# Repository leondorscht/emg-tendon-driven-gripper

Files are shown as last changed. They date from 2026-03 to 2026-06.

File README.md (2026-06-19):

# EMG Tendon-Driven Gripper

Tendon-driven robotic gripper with EMG-based open/close control. An automated Python pipeline handles calibration, threshold computation, and Arduino firmware flashing — no manual configuration needed.

Gripper Demo Video (https://youtu.be/KU1vd0XyC_Q)

---

## System Overview

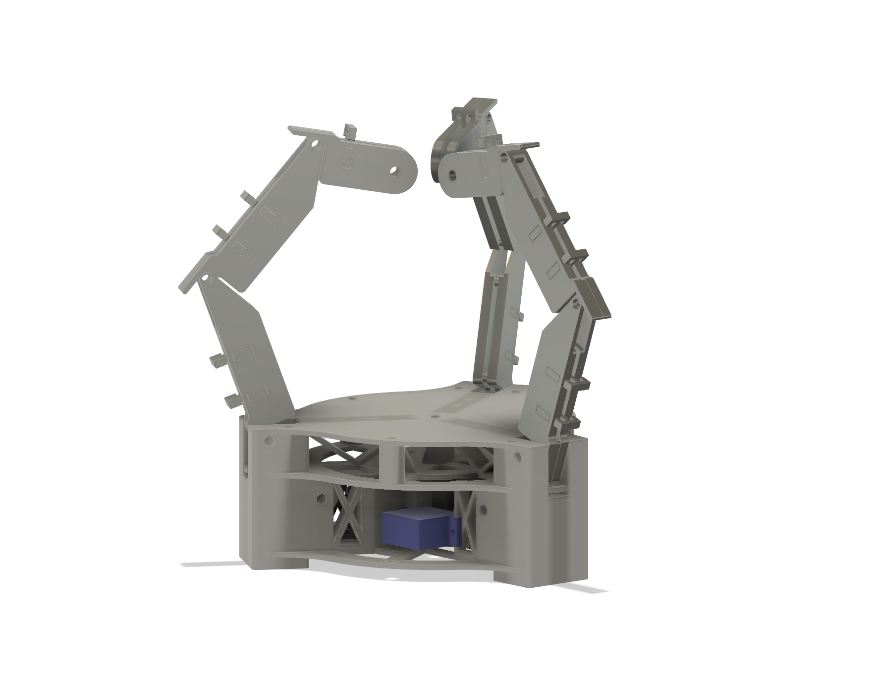
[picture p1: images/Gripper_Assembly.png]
Assembly View


*Figure 1 – Servo-based gripper assembly.*

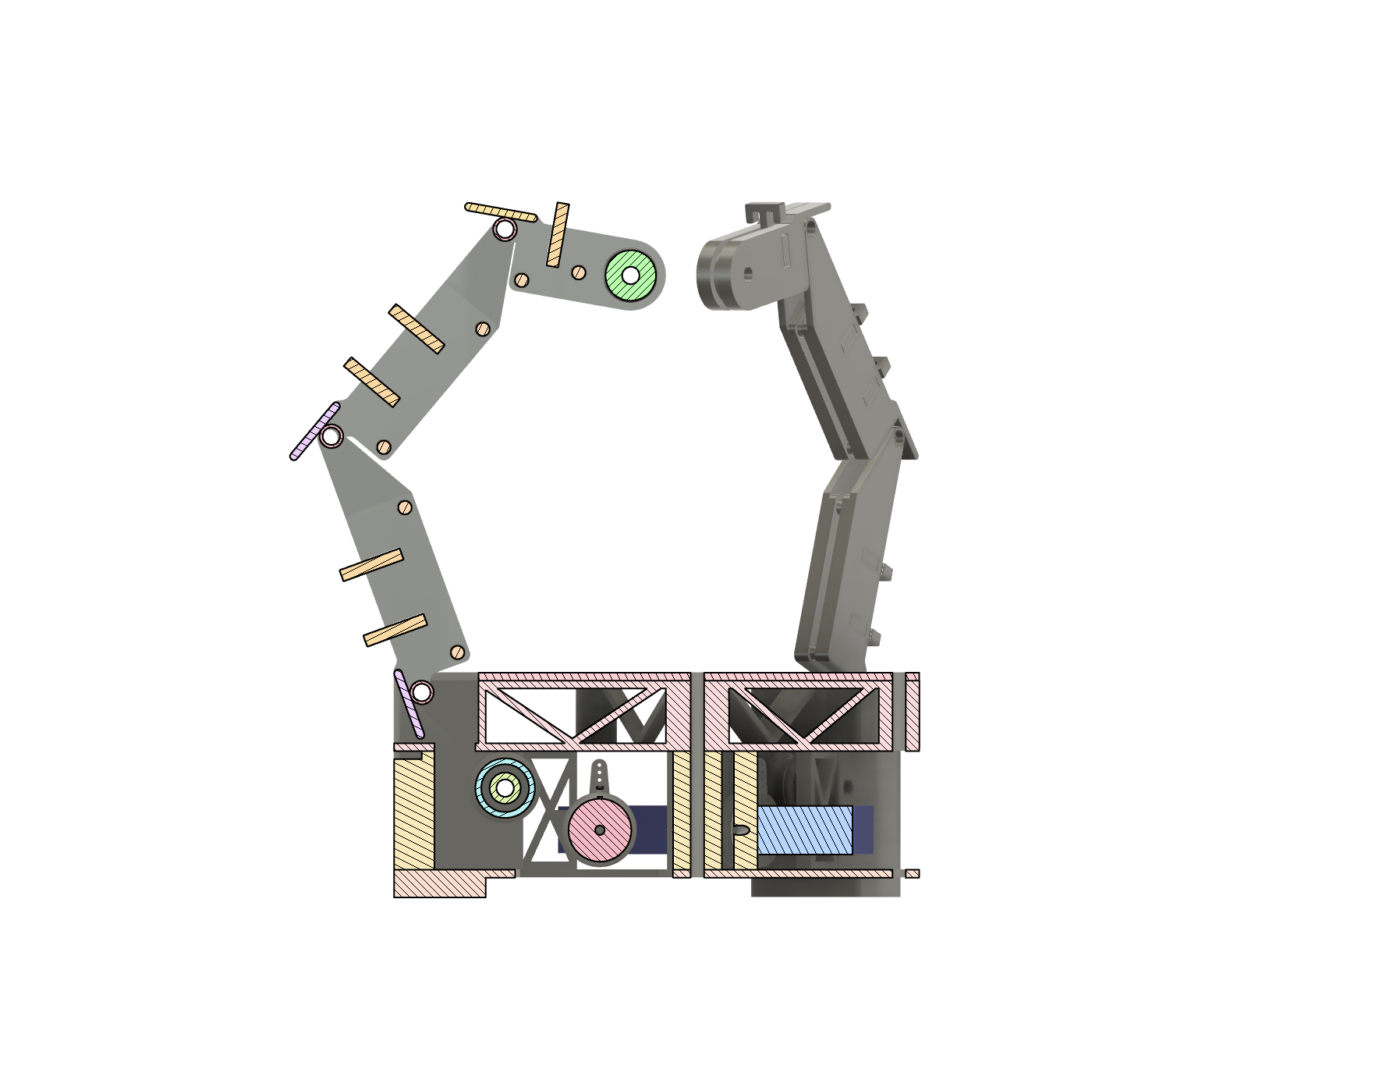
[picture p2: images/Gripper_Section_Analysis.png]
Section View


*Figure 2 – Section view highlighting internal structure, bearings and actuator integration.*

---

## Design Reference

The mechanical concept of the gripper is inspired by the tendon-driven underactuated gripper presented in:

Yi, J., Kim, B., Cho, K.-J., & Park, Y.-L. (2023).  
**Underactuated Robotic Gripper With Fiber-Optic Force Sensing Tendons.**  
IEEE Robotics and Automation Letters, 8(11), 7607–7614.  
https://doi.org/10.1109/LRA.2023.3315204

This project is **not a direct reproduction** of the original system.  
Instead, the CAD model adapts key mechanical ideas from the paper into a simplified prototype intended for rapid prototyping with 3D printing, servo-based actuation, and EMG-based control.

---

## Repository Structure

```
emg-tendon-driven-gripper/
├── arduino/
│   └── emg_controller/
│       ├── emg_controller.ino   # Arduino sketch (calibration + control modes)
│       └── config.h             # Auto-generated hardware config (do not edit manually)
├── cad/
│   ├── gripper_v1_(legacy)/     # V1 cycloidal drive concept (STEP)
│   └── gripper_v2/              # V2 servo-based design (STEP, 3MF, STL)
├── data/
│   └── calibration.csv          # EMG calibration recording output
├── images/
├── python/
│   ├── run_pipeline.py          # End-to-end pipeline entry point
│   ├── calibration_recorder.py  # EMG serial reader, protocol generator, CSV recorder
│   ├── threshold_calculator.py  # RMS-based threshold from calibration data
│   ├── config_writer.py         # Writes arduino/emg_controller/config.h
│   └── arduino_flasher.py       # Compiles and uploads via arduino-cli
└── requirements.txt
```

---

## Signal Processing

EMG control relies on two steps: baseline removal and RMS feature extraction.

**Baseline removal** – during calibration, the median of all rest-state samples is computed and stored as `EMG_BASELINE`. In control mode, the Arduino subtracts this value from each raw ADC reading before computing RMS, removing the DC offset introduced by the sensor circuit (~340 ADC on the DFRobot Gravity EMG sensor).

**RMS (Root Mean Square)** – the signal energy over a sliding window of `RMS_WINDOW` centered samples is computed as:

```
RMS = sqrt( mean( (x - baseline)^2 ) )
```

RMS is more robust than a simple mean threshold because mean values are almost identical between rest and contraction states (both dominated by the DC offset), while RMS captures the increase in signal variance during muscle activation.

**Threshold** – computed from rest-state RMS values as:

```
threshold = rest_RMS_mean + multiplier × rest_RMS_std
```

With the default `multiplier = 2.0`, approximately 97.7% of rest-state RMS values fall below the threshold. A sanity check warns if the computed threshold exceeds the active-state RMS mean, indicating a failed calibration.

**State detection** – to avoid false triggers from transient spikes, the control loop requires the RMS to exceed the threshold for `ACTIVATION_COUNT_THRESHOLD` consecutive samples before closing, and to fall below it for `RELEASE_COUNT_THRESHOLD` consecutive samples before opening.

---

## Software Pipeline

The Python pipeline in `python/run_pipeline.py` automates the full calibration-to-control workflow:

1. **Write calibration config** – generates `config.h` with `MODE_CALIBRATION=1` and a passthrough threshold
2. **Flash calibration firmware** – compiles and uploads the sketch via `arduino-cli`
3. **Record calibration data** – guides the user through a rest/active protocol and records raw EMG values to CSV
4. **Compute threshold and baseline** – calculates `EMG_BASELINE` (median of rest values) and `EMG_THRESHOLD` (rest RMS mean + multiplier × rest RMS std) from the recorded data
5. **Write control config** – regenerates `config.h` with `MODE_CALIBRATION=0`, the computed threshold, and the baseline
6. **Flash control firmware** – uploads the final sketch; the Arduino now runs RMS-based EMG threshold control

### Arduino firmware modes

The sketch switches behaviour at compile time via `MODE_CALIBRATION` in `config.h`:

- **Calibration mode** – streams raw ADC values over serial at ~200 Hz; Python handles all signal processing
- **Control mode** – computes RMS on-device after baseline subtraction, closes all servos when `rms_value > EMG_THRESHOLD` for `ACTIVATION_COUNT_THRESHOLD` consecutive samples, opens them after `RELEASE_COUNT_THRESHOLD` consecutive samples below threshold

### Running the pipeline

```bash
pip install -r requirements.txt

cd python
python run_pipeline.py \
  --port /dev/ttyUSB0 \
  --fqbn arduino:avr:nano
```

Key arguments (all have defaults):

| Argument | Default | Description |
|---|---|---|
| `--port` | *(required)* | Serial port of the Arduino |
| `--fqbn` | *(required)* | Fully Qualified Board Name for arduino-cli |
| `--servo-pins` | `9 10 11` | PWM pins for servos |
| `--servo-open-angle` | `0` | Servo angle for open state |
| `--servo-close-angle` | `180` | Servo angle for closed state |
| `--rms-window` | `32` | RMS window size in samples |
| `--activation-count-threshold` | `20` | Consecutive samples above threshold to close |
| `--release-count-threshold` | `10` | Consecutive samples below threshold to open |
| `--state-length` | `5` | Seconds per active state during calibration |
| `--rest-length` | `5` | Seconds per rest state during calibration |
| `--num-repetitions` | `5` | Number of rest/active repetitions |
| `--threshold-multiplier` | `2.0` | Multiplier on rest RMS std for threshold |

`arduino-cli` must be installed and the target board core installed (`arduino-cli core install arduino:avr` for Nano/Uno).

---

## Actuation Iterations

### V1 – Cycloidal Transmission (Legacy)
- Multi-part cycloidal drive (~30 components)
- Concept validated mechanically
- Discontinued due to speed limitations and system complexity

### V2 – Servo-Based Actuation (Current)
- Direct MG90S servo integration
- Reduced mechanical complexity
- Improved responsiveness and controllability

The current prototype uses MG90S micro servos. They were intentionally selected for the initial prototype due to their low cost, availability, and ease of integration. Future iterations may explore higher-torque servos once the mechanical design and control pipeline are fully validated.

---

## Bill of Materials (Servo Version)

- 3× MG90S Micro Servo
- 9× MR128 ZZ Ball Bearings (8×12×3.5 mm)
- Nylon monofilament line (tendon)
- M3 and M4 fasteners
- Arduino Nano (or compatible)
- EMG sensor module with analog output (e.g. DFRobot Gravity EMG Sensor)

---

## Notes on Development

The mechanical design, hardware integration, signal processing approach, and software architecture were developed independently. AI assistance (Claude) was used selectively for code refactoring and documentation only.

---

## Design Files

The mechanical design was developed in Fusion 360. STEP and 3MF files are in `cad/gripper_v2/`. STL files for printing are in `cad/gripper_v2/stl_files/`.

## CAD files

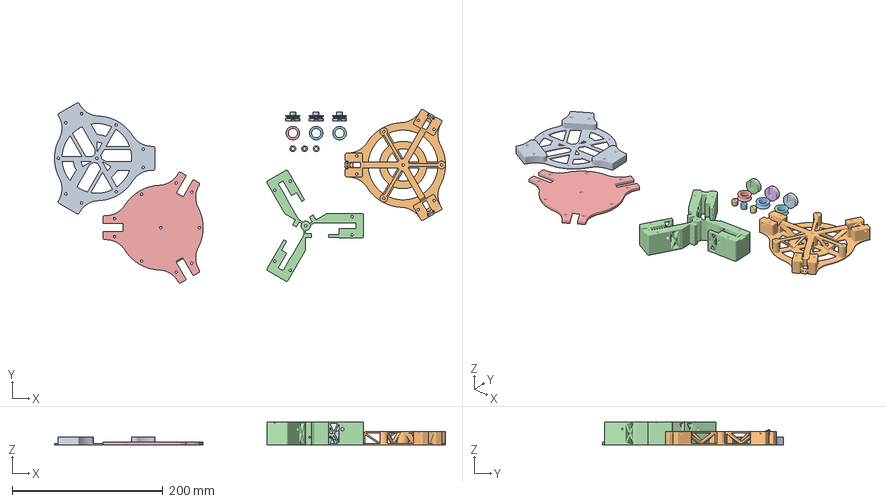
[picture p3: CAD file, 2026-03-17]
cad/gripper_v2/Gripper_Base_Print_Profile.3mf
518.5 x 239.4 x 30.0 mm
BottomPlate.stl
FingerConnectionLayer.stl
PinRoller.stl x 3
ServoMountLayer.stl
TendonRedirectionRoll.stl x 3
CableSpool.stl x 3
TopPlate.stl

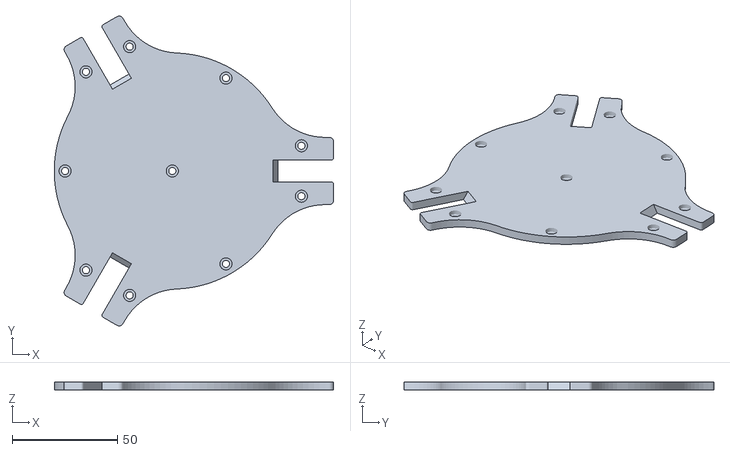
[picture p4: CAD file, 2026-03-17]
cad/gripper_v2/stl_files/base/TopPlate.stl
133.0 x 147.6 x 4.00

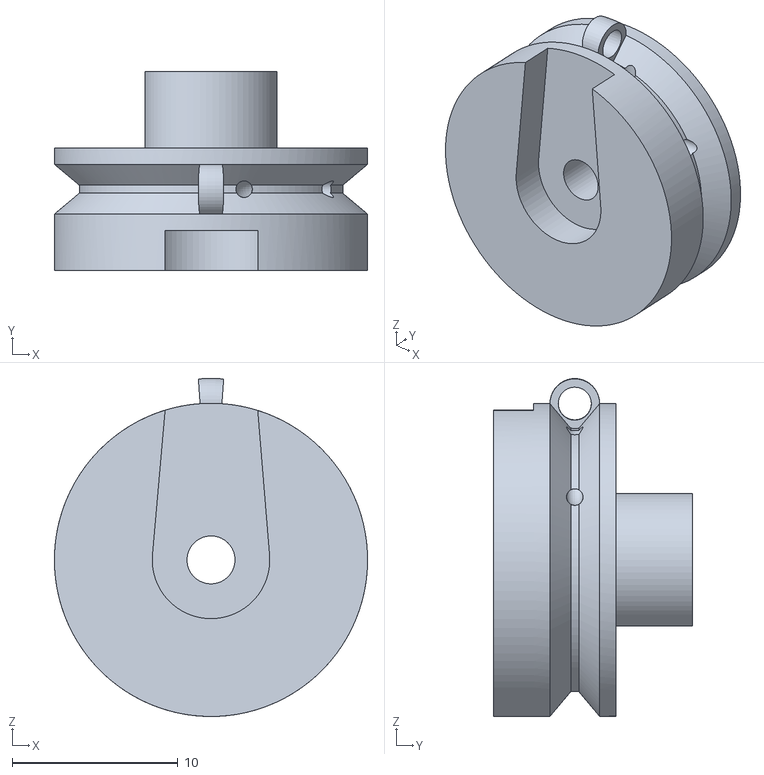
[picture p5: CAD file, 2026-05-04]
cad/gripper_v2/stl_files/CableSpool.stl
18.9 x 12.0 x 20.4

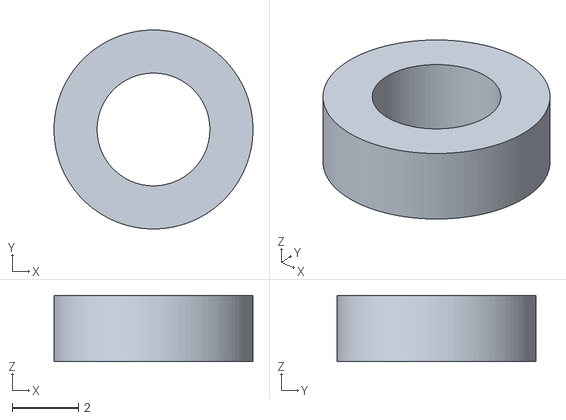
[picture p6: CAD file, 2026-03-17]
cad/gripper_v2/stl_files/finger/Spacer.stl
6.00 x 6.00 x 2.00

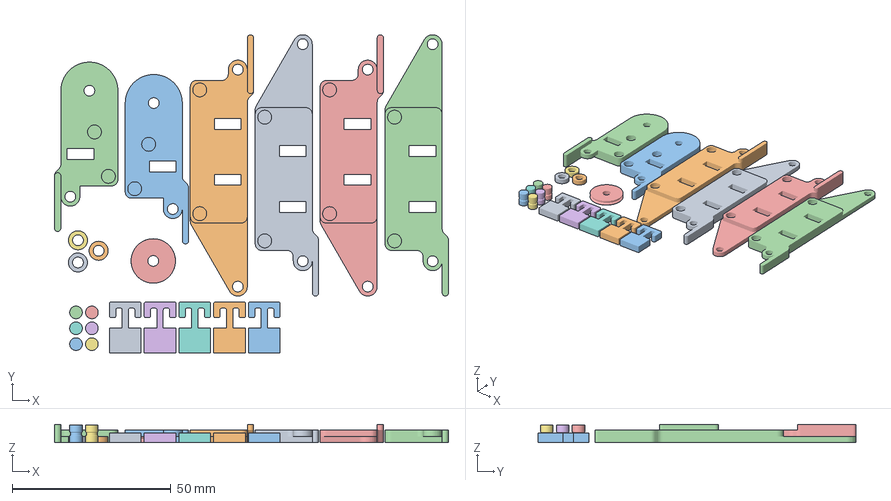
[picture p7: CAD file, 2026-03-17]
cad/gripper_v2/Finger_Print_Profile.3mf
124.2 x 100.4 x 5.80 mm
MiddlePlateBottom.stl x 2
MiddlePlateTop.stl x 2
TipPlateBottom.stl
TipPlateTop.stl
EndSpool.stl
Connector.stl x 5
Spacer.stl x 3
Roller.stl x 6

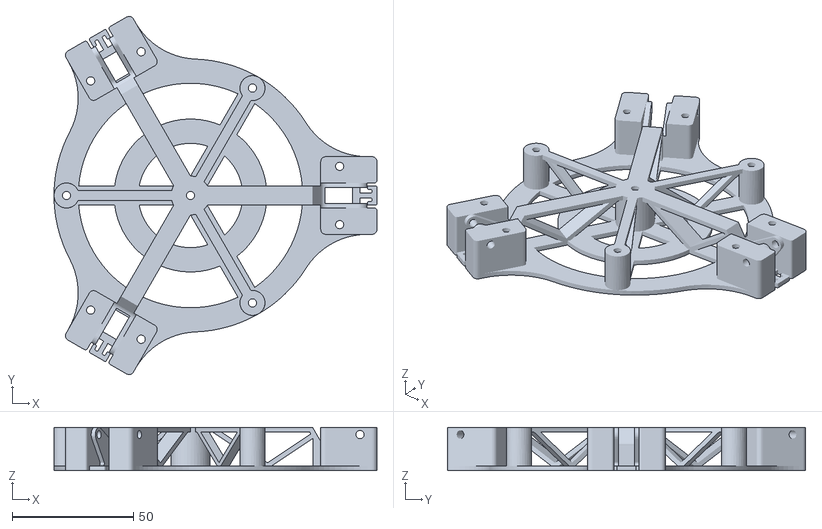
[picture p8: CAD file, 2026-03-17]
cad/gripper_v2/stl_files/base/FingerConnectionLayer.stl
133.0 x 147.6 x 17.9

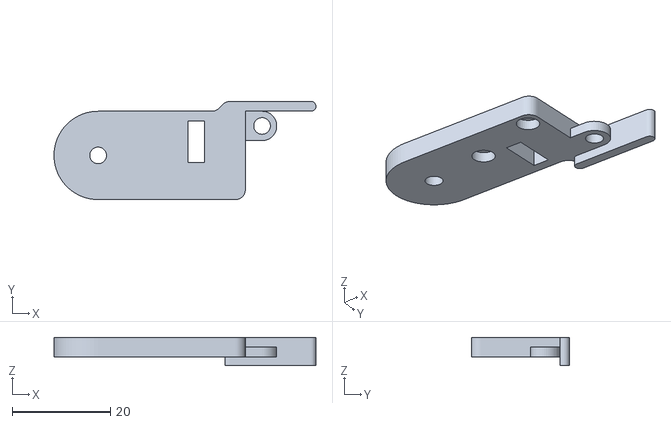
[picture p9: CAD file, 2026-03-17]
cad/gripper_v2/stl_files/finger/TipPlateTop.stl
53.4 x 20.0 x 5.80

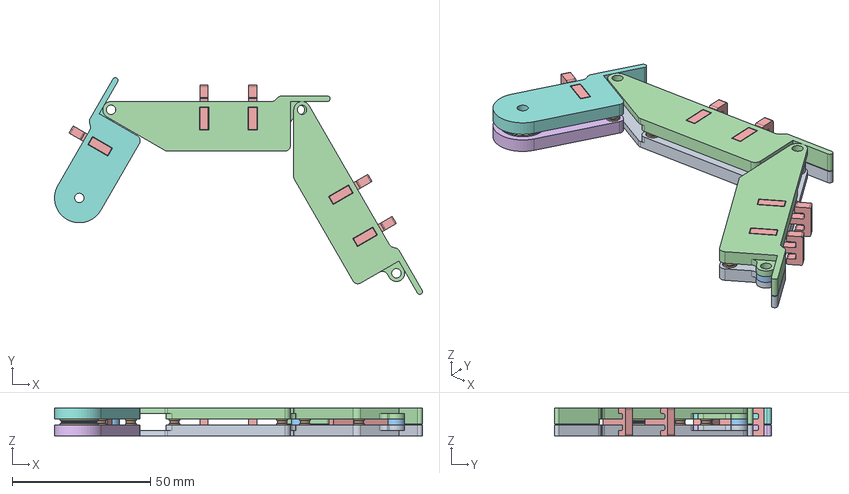
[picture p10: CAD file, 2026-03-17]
cad/gripper_v2/Finger_Redesign.step
133.3 x 78.5 x 10.0 mm
MiddlePlateBottom x 2
Roller x 6
Spacer x 3
MiddlePlateTop x 2
Connector x 5
TipPlateBottom
EndSpool
TipPlateTop

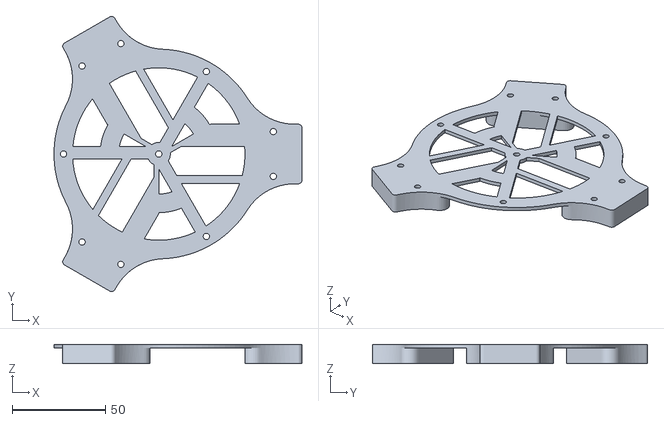
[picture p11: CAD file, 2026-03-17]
cad/gripper_v2/stl_files/base/BottomPlate.stl
133.0 x 147.6 x 10.4

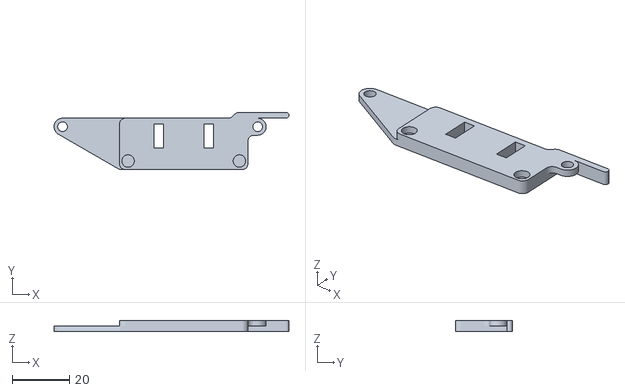
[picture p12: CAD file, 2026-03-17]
cad/gripper_v2/stl_files/finger/MiddlePlateBottom.stl
82.4 x 20.0 x 4.00

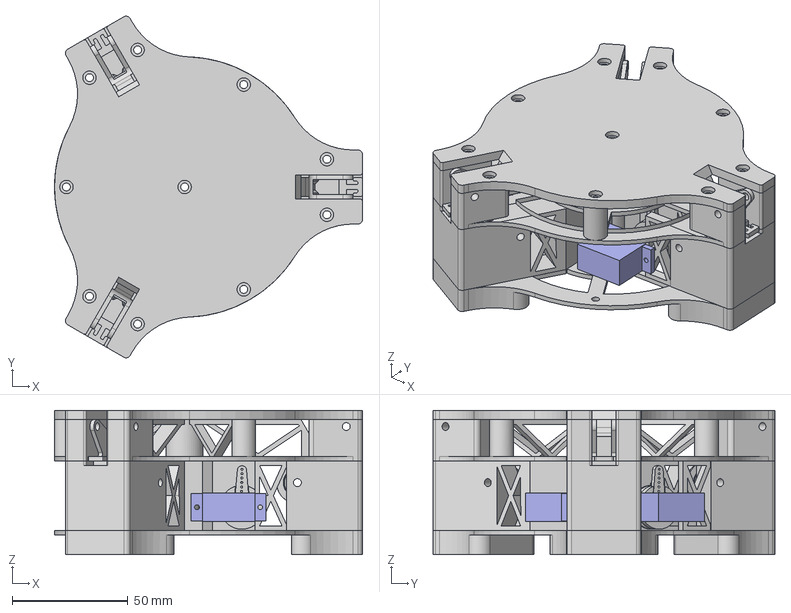
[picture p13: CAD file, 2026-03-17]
cad/gripper_v2/Gripper_Base.step
133.0 x 147.6 x 62.3 mm
TopPlate
FingerConnectionLayer
Rolle x 3
PinRoller x 3
mg90arm x 3
SERVO_SG90 x 3
MR128ZZ1 Outer Ring x 9
MR128ZZ1 Inner Ring x 9
MR128ZZ1 Shield1 x 9
MR128ZZ1 Ball x 180
MR128ZZ1 Shield2 x 9
BottomPlate

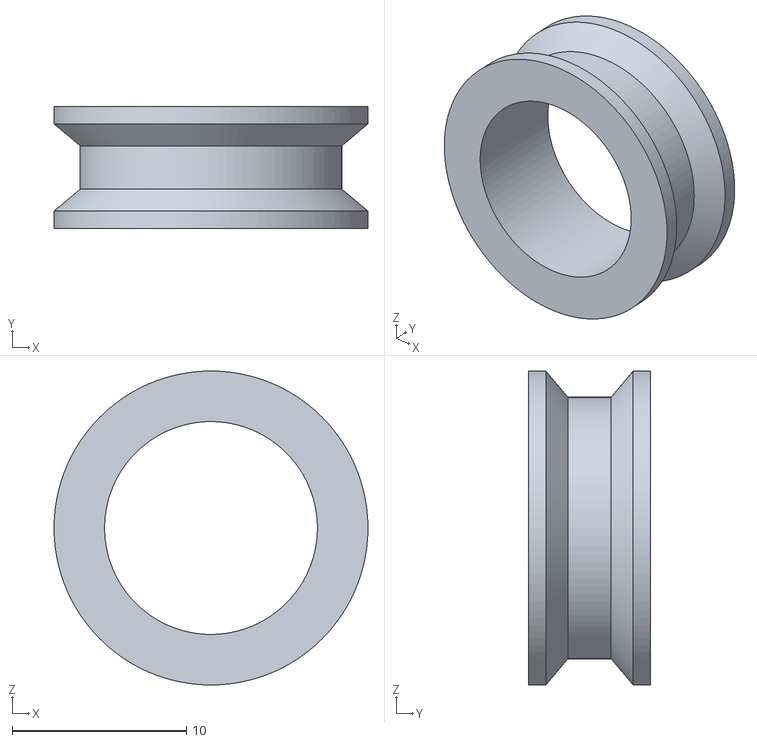
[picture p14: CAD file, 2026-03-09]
cad/gripper_v2/stl_files/base/TendonRedirectionRoll.stl
18.0 x 7.00 x 18.0

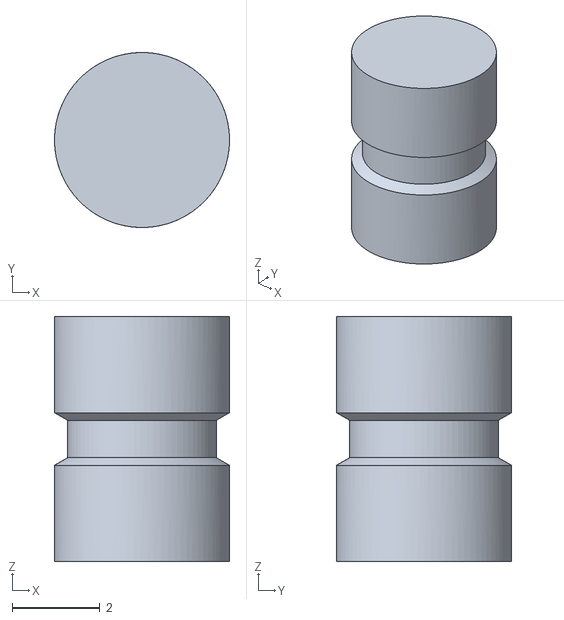
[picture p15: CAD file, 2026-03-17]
cad/gripper_v2/stl_files/finger/Roller.stl
4.00 x 4.00 x 5.60

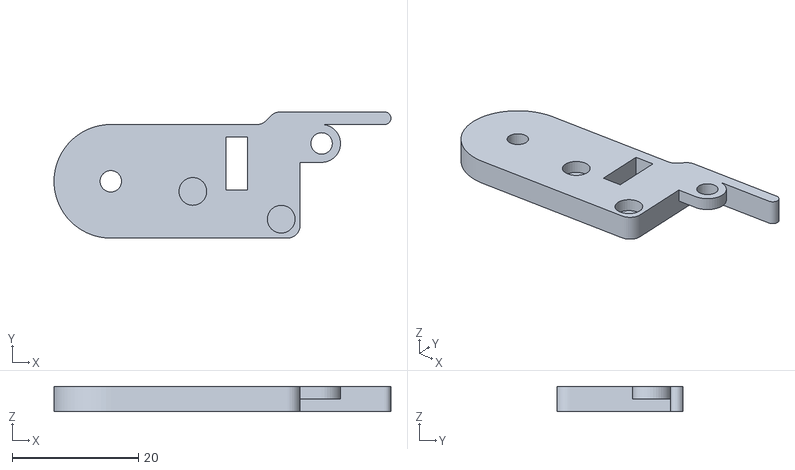
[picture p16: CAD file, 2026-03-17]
cad/gripper_v2/stl_files/finger/TipPlateBottom.stl
53.4 x 20.0 x 4.00

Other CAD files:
cad/gripper_v2/stl_files/base/CableSpool.stl
cad/gripper_v2/stl_files/base/ServoMountLayer.stl
cad/gripper_v2/stl_files/finger/EndSpool.stl
cad/gripper_v2/stl_files/base/PinRoller.stl
cad/gripper_v1_(legacy)/Cycloidal_Gear_Drive.step
cad/gripper_v2/stl_files/finger/Connector.stl
cad/gripper_v2/stl_files/finger/MiddlePlateTop.stl

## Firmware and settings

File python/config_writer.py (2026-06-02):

from pathlib import Path
import argparse
import textwrap


class ConfigWriter:
    def __init__(self, config_path):
        self.config_path = Path(config_path)

    def format_servo_pins(self, servo_pins):
        if len(servo_pins) == 0:
            raise ValueError("Servo pin list cannot be empty")

        pin_string = "{"
        for pin in servo_pins:
            pin_string += str(pin)
            pin_string += ","

        pin_string = pin_string[:-1]
        pin_string += "}"

        return pin_string

    def build_config_content(
        self,
        mode_calibration,
        serial_baudrate,
        emg_pin,
        emg_threshold,
        emg_baseline,
        rms_window,
        activation_count_threshold,
        release_count_threshold,
        servo_pins,
        servo_open_angle,
        servo_close_angle,
        smoothing_window,
    ):
        mode_calibration = 1 if mode_calibration else 0
        pin_string = self.format_servo_pins(servo_pins)

        config_content = textwrap.dedent("""\
            #pragma once

            // Operation Mode
            // set the mode to either calibration (1) or control (0)
            #define MODE_CALIBRATION {mode_calibration}

            // Serial
            #define SERIAL_BAUDRATE {serial_baudrate}

            // Servos
            #define NUM_SERVOS {num_servos}
            const int SERVO_PINS[NUM_SERVOS] = {pin_string};

            #define SERVO_OPEN_ANGLE {servo_open_angle}
            #define SERVO_CLOSE_ANGLE {servo_close_angle}

            // EMG
            #define EMG_PIN {emg_pin}
            #define EMG_THRESHOLD {emg_threshold}
            #define EMG_BASELINE {emg_baseline}

            // RMS feature extraction
            #define RMS_WINDOW {rms_window}

            // State detection timing
            #define ACTIVATION_COUNT_THRESHOLD {activation_count_threshold}
            #define RELEASE_COUNT_THRESHOLD {release_count_threshold}

            // Legacy smoothing value, currently unused
            #define EMG_SMOOTHING_WINDOW {smoothing_window}
            """).format(
                mode_calibration=mode_calibration,
                serial_baudrate=serial_baudrate,
                num_servos=len(servo_pins),
                pin_string=pin_string,
                servo_open_angle=servo_open_angle,
                servo_close_angle=servo_close_angle,
                emg_pin=emg_pin,
                emg_threshold=emg_threshold,
                emg_baseline=emg_baseline,
                rms_window=rms_window,
                activation_count_threshold=activation_count_threshold,
                release_count_threshold=release_count_threshold,
                smoothing_window=smoothing_window,
            )

        return config_content

    def write_config(
        self,
        mode_calibration=True,
        serial_baudrate=9600,
        emg_pin="A0",
        emg_threshold=1023,
        emg_baseline=350,
        rms_window=32,
        activation_count_threshold=20,
        release_count_threshold=10,
        servo_pins=None,
        servo_open_angle=0,
        servo_close_angle=90,
        smoothing_window=10,
    ):
        if servo_pins is None:
            servo_pins = [9, 10, 11]

        config_string = self.build_config_content(
            mode_calibration=mode_calibration,
            serial_baudrate=serial_baudrate,
            emg_pin=emg_pin,
            emg_threshold=emg_threshold,
            emg_baseline=emg_baseline,
            rms_window=rms_window,
            activation_count_threshold=activation_count_threshold,
            release_count_threshold=release_count_threshold,
            servo_pins=servo_pins,
            servo_open_angle=servo_open_angle,
            servo_close_angle=servo_close_angle,
            smoothing_window=smoothing_window,
        )

        self.config_path.parent.mkdir(parents=True, exist_ok=True)
        self.config_path.write_text(config_string, encoding="utf-8")


def parse_args():
    parser = argparse.ArgumentParser()
    parser.add_argument("--config-path", required=True)
    parser.add_argument("--mode-calibration", type=int, required=True)
    parser.add_argument("--serial-baudrate", type=int, default=9600)
    parser.add_argument("--emg-pin", default="A0")
    parser.add_argument("--emg-threshold", type=int, default=400)
    parser.add_argument("--emg-baseline", type=int, default=350)
    parser.add_argument("--rms-window", type=int, default=32)
    parser.add_argument("--activation-count-threshold", type=int, default=20)
    parser.add_argument("--release-count-threshold", type=int, default=10)
    parser.add_argument("--servo-pins", type=int, nargs="+", required=True)
    parser.add_argument("--servo-open-angle", type=int, default=0)
    parser.add_argument("--servo-close-angle", type=int, default=90)
    parser.add_argument("--smoothing-window", type=int, default=10)
    return parser.parse_args()


def main():
    args = parse_args()

    writer = ConfigWriter(config_path=args.config_path)

    writer.write_config(
        mode_calibration=bool(args.mode_calibration),
        serial_baudrate=args.serial_baudrate,
        emg_pin=args.emg_pin,
        emg_threshold=args.emg_threshold,
        emg_baseline=args.emg_baseline,
        rms_window=args.rms_window,
        activation_count_threshold=args.activation_count_threshold,
        release_count_threshold=args.release_count_threshold,
        servo_pins=args.servo_pins,
        servo_open_angle=args.servo_open_angle,
        servo_close_angle=args.servo_close_angle,
        smoothing_window=args.smoothing_window,
    )


if __name__ == "__main__":
    main()

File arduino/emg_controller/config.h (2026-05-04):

#pragma once

// Operation Mode
// set the mode to either calibration (1) or control (0)
#define MODE_CALIBRATION 1

// Serial
#define SERIAL_BAUDRATE 9600

// Servos
#define NUM_SERVOS 3
const int SERVO_PINS[NUM_SERVOS] = {9, 10, 11};

#define SERVO_OPEN_ANGLE 0
#define SERVO_CLOSE_ANGLE 90

// EMG
#define EMG_PIN A0
#define EMG_THRESHOLD 400
#define EMG_SMOOTHING_WINDOW 10

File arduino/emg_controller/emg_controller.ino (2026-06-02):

#include "config.h"
#include <Servo.h>
#include <math.h>

Servo servos[NUM_SERVOS];

// RMS buffer
int rms_buffer[RMS_WINDOW];
int rms_index = 0;
bool rms_filled = false;

// State detection
bool is_closed = false;
int activation_counter = 0;
int release_counter = 0;

void setup() {
  Serial.begin(SERIAL_BAUDRATE);

#if MODE_CALIBRATION
  setup_calibration();
#else
  setup_control();
#endif
}

void loop() {
#if MODE_CALIBRATION
  calibration_loop();
#else
  control_loop();
#endif
}

void setup_calibration() {
  // Analog input does not need setup
}

void setup_control() {
  for (int i = 0; i < NUM_SERVOS; i++) {
    servos[i].attach(SERVO_PINS[i]);
  }
  set_all_servos(SERVO_CLOSE_ANGLE);

  delay(1000);

  set_all_servos(SERVO_OPEN_ANGLE);
}

void calibration_loop() {
  // During calibration we send RAW values.
  // Python calculates baseline and RMS threshold from these.
  int raw_value = analogRead(EMG_PIN);

  Serial.println(raw_value);

  delay(5);
}

void control_loop() {
  int emg_value = read_emg_rms();

  if (!is_closed) {
    if (emg_value > EMG_THRESHOLD) {
      activation_counter++;
    } else {
      activation_counter = 0;
    }

    if (activation_counter >= ACTIVATION_COUNT_THRESHOLD) {
      is_closed = true;
      set_all_servos(SERVO_CLOSE_ANGLE);
      activation_counter = 0;
      release_counter = 0;
    }
  } else {
    if (emg_value < EMG_THRESHOLD) {
      release_counter++;
    } else {
      release_counter = 0;
    }

    if (release_counter >= RELEASE_COUNT_THRESHOLD) {
      is_closed = false;
      set_all_servos(SERVO_OPEN_ANGLE);
      release_counter = 0;
      activation_counter = 0;
    }
  }

  Serial.println(emg_value);

  delay(5);
}

void set_all_servos(int servo_angle) {
  for (int i = 0; i < NUM_SERVOS; i++) {
    servos[i].write(servo_angle);
  }
}

int read_emg_rms() {
  int raw = analogRead(EMG_PIN);

  int centered = raw - EMG_BASELINE;

  rms_buffer[rms_index] = centered;
  rms_index++;

  if (rms_index >= RMS_WINDOW) {
    rms_index = 0;
    rms_filled = true;
  }

  int count = rms_filled ? RMS_WINDOW : rms_index;

  if (count == 0) {
    return 0;
  }

  long sum_sq = 0;

  for (int i = 0; i < count; i++) {
    long v = rms_buffer[i];
    sum_sq += v * v;
  }

  float mean_sq = (float)sum_sq / count;

  return (int)sqrt(mean_sq);
}

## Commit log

2026-03-03 Update README.md
    Updated BOM
2026-03-03 Feat: Current design files in STEP format.
    [Cycloidal_Gear_Drive.step, Finger_Redesign.step, Gripper_Base.step]
2026-03-09 Fix & style: adjust screw hole diameter for servo mount and actuator spool. Add heat-set inserts to bottom plate (related to #3). Rename components and bodies.
    [Gripper_Base.step]
2026-03-09 Docs: document actuator choice (MG90S servos)
2026-03-09 chore: add stl files
    [BottomPlate.stl, CableSpool.stl, FingerConnectionLayer.stl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]
2026-03-09 chore: base printing file with no infill around heat set inserts
    [Gripper_Base_Print_Profile.3mf]
2026-03-11 fix: no empty spaces in print profile around heat-set inserts
    [Gripper_Base_Print_Profile.3mf]
2026-03-17 feat(mech): replace M4 fasteners with M3 and adjust finger-to-base angle
    - Replaced M4 bolts with M3 wherever geometry allows
    - Updated finger-to-base angle for improved tendon routing
    - Closes #3
    [Finger_Redesign.step, Gripper_Base.step]
2026-03-17 chore(mech): update STL and print files for M3 revision add stl for finger
    Follows #3
    [BottomPlate.stl, CableSpool.stl, Connector.stl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]
2026-03-17 chore(mech): change print profile for base add finger print profile
    [Finger_Print_Profile.3mf, Gripper_Base_Print_Profile.3mf]
2026-05-04 feat(mech): the cable spool is more stable, as the string will go through a tunnel inside of it, making it more stable than on the outside
    [CableSpool.stl]
2026-05-04 feat(arduino): add EMG-based control firmware with calibration and control modes
    - implement dual-mode architecture (calibration / control)
    - add EMG signal acquisition via analog input
    - implement moving average smoothing
    - add threshold-based servo control
    - support multiple servos via array
    - introduce config.h for runtime configuration
    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
2026-05-04 feat(python): recorder utility functions that can generate objects to conduct the calibration, incl. data writing in data folder
2026-05-04 feat(python): implement modular EMG calibration recording pipeline
    - add ProtocolGenerator for state-based recording sequences
    - implement EMGSerialReader for Arduino serial input
    - implement CSVRecorder with automatic directory creation
    - add RecordingController to coordinate recording process
    - return output path after recording for pipeline integration
    - add CLI interface for standalone usage
    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
2026-05-04 feat(python): implement EMG threshold calculation from calibration data
    - add ThresholdCalculator for computing activation threshold
    - load and group EMG values by state from CSV
    - compute threshold using mean + k * std from rest state
    - support multiple active states for validation
    - add sanity check to detect poor signal separation
    - provide CLI interface for standalone usage
    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
2026-05-04 feat(python): implement Arduino config writer for EMG control
    - generate config.h from Python parameters
    - support calibration/control mode switching
    - format servo pin arrays for Arduino
    - add validation for servo configuration
    - use template-based config generation with textwrap
    - write config file with automatic directory creation
    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
2026-05-04 feat(python): add Arduino flasher using arduino-cli
    - implement compile and upload commands via subprocess
    - add command builders for compile and upload
    - include error handling with stdout/stderr output
    - validate sketch path before flashing
    - support configurable CLI path, port and board (FQBN)
    Enables automated firmware flashing from Python pipeline.
    Refs #15
    [arduino_flasher.py]
2026-05-04 feat(pipeline): implement end-to-end EMG calibration and control pipeline
    - integrate calibration recording, threshold calculation, and config generation
    - automate firmware compilation and flashing via arduino-cli
    - support calibration and control modes through dynamic config.h generation
    - orchestrate full pipeline in run_pipeline.py
    Enables one-command execution from EMG calibration to real-time control.
    Closes #16
2026-05-04 Fix(arduino): Fix wrong function call of read_smooted_emg
    [emg_controller.ino]
2026-05-04 Fix(python): change wrong path to arduino file
    [run_pipeline.py]
2026-05-05 Fix(Python): Edit the standard arguments for the pipeline
    [run_pipeline.py]
2026-05-07 fix(mechatronic): change the servo angles to match gripper design
    [run_pipeline.py]
2026-06-19 Add demo video link to README
    Added a demo video link for the gripper.
